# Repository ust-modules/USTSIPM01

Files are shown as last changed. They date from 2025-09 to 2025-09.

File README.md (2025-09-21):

# USTSIPM01 — Silicon photomultiplier (SiPM) interface module  

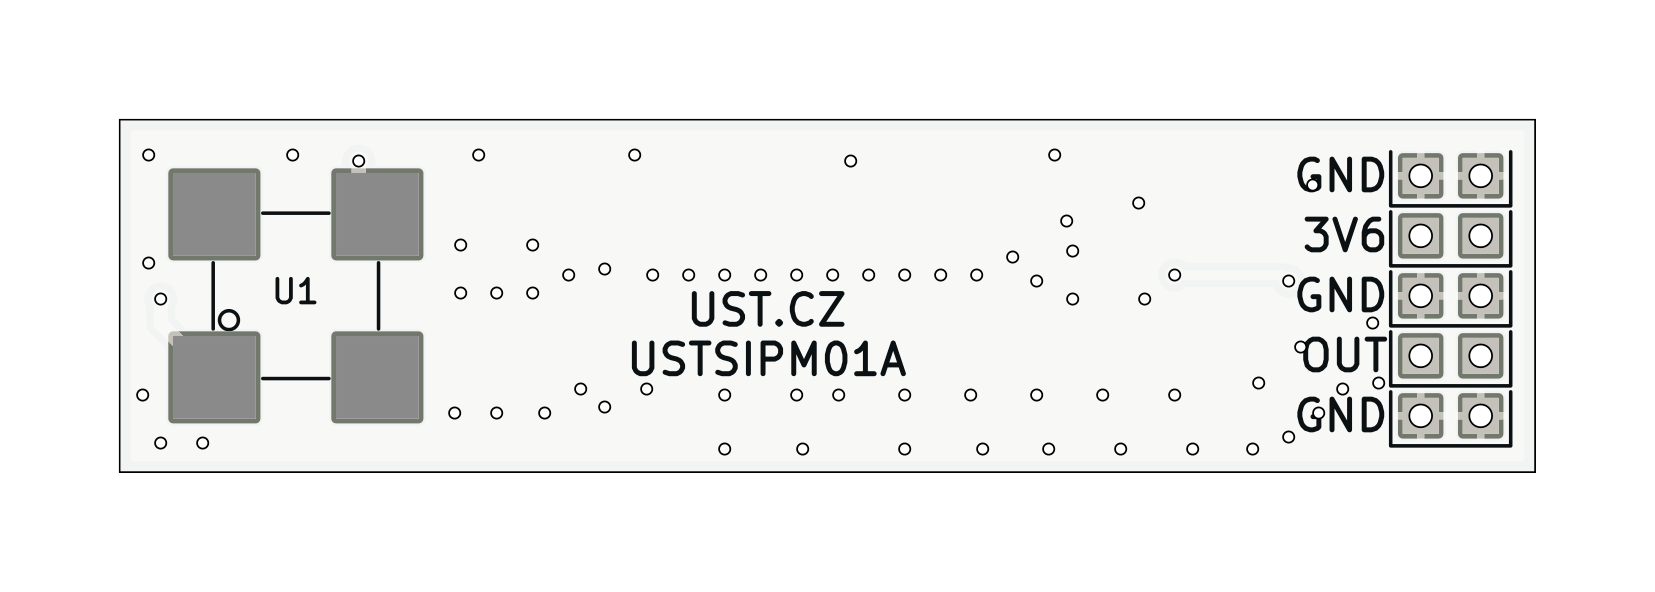
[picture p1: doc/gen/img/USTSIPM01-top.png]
Top view on USTSIPM01A

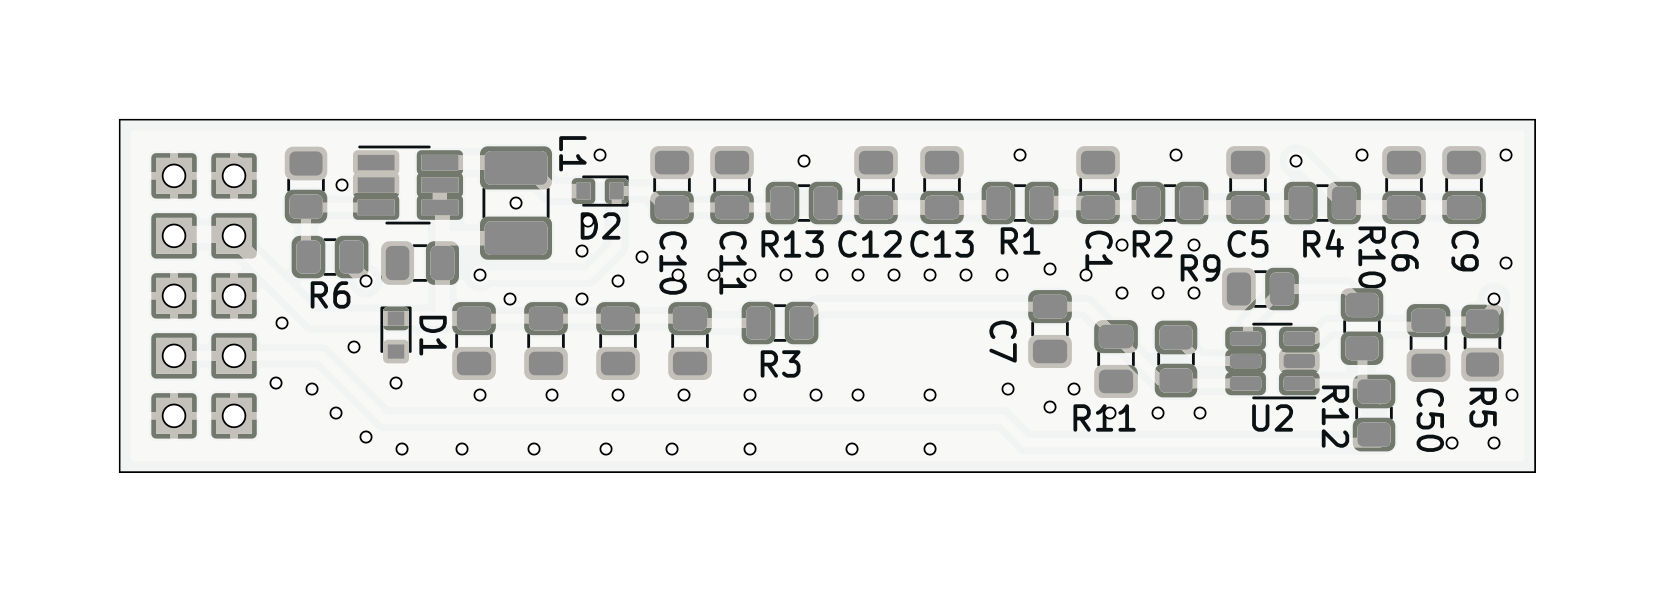
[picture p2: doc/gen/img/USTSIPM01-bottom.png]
Bottom view on USTSIPM01A


Complete analog front‑end for Silicon Photomultipliers (SiPM). The module provides resistor-configurable high‑voltage bias for the SiPM sensor and a low‑noise, wideband readout stage suitable for timing and amplitude measurements.

## Features

* Footprint for onsemi **MicroFC‑60035‑SMT** SiPM (6×6 mm, 35 µm microcells).
* On‑board high‑voltage boost converter MAX5026 generating the SiPM bias from the +5 V rail.
* Precision feedback network with design equation Vout = 1.25 V × (1 + R2/R3); default configuration targets to 31.7 V bias.
* Low‑noise **wideband amplifier** stage OPA836 for SiPM signal readout.
* Pin-header connector for lab bring‑up and diagnostics.

## Block Diagram

```mermaid
flowchart LR
    V["3V6"] -->|Bias supply| MAX5026["MAX5026 Boost"]
    MAX5026 -->|VBIAS 25-32 V| SiPM["SiPM MicroFC-60035"]
    SiPM -->|A| OPA836["OPA836 Readout"]
    OPA836 --> OUT["OUT"]
    V33["+3.3 V"] --> OPA836
```

## Electrical Characteristics (module)

* Supply rails: +3.6 V (bias converter), +3.3 V (analog stage).
* SiPM bias range: designable in \~25–32 V via resistor ratio (see below). Default assembly ≈ 31.7 V.
* Output: single‑ended, wideband path suitable for 50 Ω instrumentation (use external 50 Ω termination at scope/DAQ as required).

> Note (SiPM operating point): The sensor is biased at Vout = VBR + VOV, where VBR is the device’s breakdown voltage and VOV is the selected overvoltage. Typical recommended VOV = 1…5 V. Temperature coefficient of VBR ≈ +21.5 mV/°C (adjust bias accordingly).

## Bias Network Design

The MAX5026 feedback follows:

```
Vout = 1.25 V × (1 + R2/R3)
```

**Default population** (R2 = 3.9 MΩ, R3 = 160 kΩ) yields:

```
Vout ≈ 1.25 × (1 + 3.9M/160k) ≈ 31.7 V
```

**Example design** for MicroFC‑60035 with typical VBR ≈ 24.7 V:

* For **VOV = 3.0 V** → target **Vout ≈ 27.7 V**.
* Choose standard values to satisfy 1.25 × (1 + R2/R3) ≈ 27.7. For example, **R3 = 160 kΩ**, **R2 ≈ 3.394 MΩ** (use 3.40 MΩ or parallel combination). Verify with measurement on the assembled board.

> Keep the feedback resistors in the **MΩ** range to minimize divider current, and place them tight to the FB node. Use a low‑leakage layout around FB.
> Treat the SiPM and the module as **ESD‑sensitive**.

## Operating Guidance

* Start at low overvoltage (e.g., +1…2 V above the measured VBR) and increase gradually while monitoring dark count and pulse shape.
* Observe the maximum average current rating of the chosen sensor (for 6×6 mm devices typically tens of mA). Avoid saturating the device with continuous high optical flux.

## Changeable Parameters

* **SiPM bias (R2/R3):** select to set the required overvoltage window for the specific sensor lot and operating temperature.
* **OPA836 gain (R10/R12):** non‑inverting stage; A\_v = 1 + R10/R12. Default R10 = 12 kΩ, R12 = 1 kΩ → A\_v ≈ 13 V/V (\~22.3 dB). Adjust these resistors to set the desired voltage gain. (See schematic).

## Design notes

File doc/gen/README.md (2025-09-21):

# PCB

Board size: 60.0x15.0 mm (2.36x0.59 inches)

- This is the size of the rectangle that contains the board
- Thickness: 1.6 mm (63 mils)
- Material: FR4
- Finish: None
- Layers: 2
- Copper thickness: 35 µm

Solder mask: TOP / BOTTOM

- Color: Green

Silk screen: TOP / BOTTOM

- Color: White

Stackup:

| Name | Type | Color | Thickness [µm]| Material | Er | Loss tan |
|---|---|---|---|---|---|---|
| F.SilkS | Top Silk Screen | | | | | |
| F.Paste | Top Solder Paste | | | | | |
| F.Mask | Top Solder Mask | Green | 10 | | | |
| F.Cu | copper | | 35 | | | |
| dielectric 1 | core | | 1510 | FR4 | 4.5 | 0.020 |
| B.Cu | copper | | 35 | | | |
| B.Mask | Bottom Solder Mask | Green | 10 | | | |
| B.Paste | Bottom Solder Paste  | | | | | |
| B.SilkS | Bottom Silk Screen | | | | | |

# Important sizes

Clearance: 0.2 mm (8 mils)

Track width: 0.4 mm (16 mils)

- By design rules: 0.2 mm (8 mils)

Drill: 0.5 mm (20 mils)

- Vias: 0.5 mm (20 mils) [Design: 0.4 mm (16 mils)]
- Pads: 1.0 mm (39 mils)
- The above values are real drill sizes, they add 0.1 mm (4 mils) to plated holes (PTH)

Via: 0.8/0.4 mm (31/16 mils)

- By design rules: 0.4/0.3 mm (16/12 mils)
- Micro via: yes [0.2/0.1 mm (8/4 mils)]
- Buried/blind via: yes
- Total: 68 (thru: 68 buried/blind: 0 micro: 0)

Outer Annular Ring: 0.15 mm (6 mils)

- By design rules: 0.15 mm (6 mils)

Eurocircuits class: 4B
- Using min drill 0.5 mm for an OAR of 0.15 mm

# General stats

Components count: (SMD/THT)

- Top: 0/6 (THT)
- Bottom: 33/0 (SMD)

Defined tracks:

- 0.4 mm (16 mils)
- 0.5 mm (20 mils)
- 0.6 mm (24 mils)
- 0.8 mm (31 mils)
- 1.0 mm (39 mils)

Used tracks:

- 0.4 mm (16 mils) (55) defined: yes
- 0.6 mm (24 mils) (56) defined: yes

Defined vias:

- 0.8/0.4 mm (31/16 mils)

Used vias:

- 0.8/0.4 mm (31/16 mils) (Count: 68, Aspect: 2.0 A) defined: yes

Holes (excluding vias):

- 0.89 mm (35 mils) (10)

Oval holes:

Drill tools (including vias and computing adjusts and rounding):

- 0.5 mm (20 mils) (68)
- 1.0 mm (39 mils) (10)

Solder paste stats:

Using a paste with 87.75 % alloy, that has an specific gravity for the alloy of 7.4 g/cm³
and 1.0 g/cm³ for the flux. This paste has an specific gravity of  4.15 g/cm³.

The stencil thickness is  0.12 mm.

| Side | Pads with paste | Area [mm²] | Paste [g] |
|---|---|---|---|
| Top | 4 | 49.00 | 0.24 |
| Bottom | 74 | 97.40 | 0.48 |
| Total  | 78 | 146.40 | 0.73 |

Note: this is just an approximation to the theoretical value. Margins of the solder mask and waste aren't computed.

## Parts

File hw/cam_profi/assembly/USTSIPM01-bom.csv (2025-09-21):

Component | Description | Part | References | Value | Footprint | Quantity Per PCB | Datasheet | ust_id
1 | Unpolarized capacitor | C | C9 | 10nF | C_0805_2012Metric | 1 | ~ | 5c70984712875079b91f8b49
2 |  | C-Device | C11C12 | 100nF | C_0805_2012Metric | 2 |  | 5c70984712875079b91f8b4c
3 | Unpolarized capacitor | C | C5C6C8C50 | 100nF | C_0805_2012Metric | 4 | ~ | 5c70984712875079b91f8b4c
4 | Unpolarized capacitor | C | C3C4C7C14C15 | 10uF | C_0805_2012Metric | 5 | ~ | 5c70984712875079b91f8b53
5 |  | C-Device | C2 | 10uF | C_0805_2012Metric | 1 |  | 5c70984712875079b91f8b53
6 | Unpolarized capacitor | C | C1 | 10uF/35V | C_0805_2012Metric | 1 | ~ | 628d183cdc56076e9a223682
7 |  | C-Device | C10C13 | 1uF/50V | C_0805_2012Metric | 2 |  | 5c70984712875079b91f8b6f
8 |  | D_ZENER | D1 | BZX585-B5V6.115 | D_SOD-523 | 1 |  | 60879d38128750769ee58e48
9 |  | D_Schottky-Device | D2 | NSR05T40XV2T5G | D_SOD-523 | 1 | https://www.onsemi.com/pdf/datasheet/nsr05t40xv2-d.pdf | 5c70984712875079b91f8b7b
10 | 2x01 2.54 mm pitch header, 2 pins next to each other are connected | HEADER_2x01_PARALLEL | J4J5J6J8J9 | HEADER_2x01_PARALLEL | Straight_2x01 | 5
11 |  | L_Small-Device | L1 | 400uH cca 0,9mA NLV10JT391 | L_1210_3225Metric_Pad1.42x2.65mm_HandSolder | 1 |  | 628d18f5dc56076e9a2236a9
12 | Resistor | R | R2R4R5 | 10R | R_0805_2012Metric | 3 | ~ | 5c70984512875079b91f896d
13 | Resistor | R | R1R3 | 100R | R_0805_2012Metric | 2 | ~ | 5c70984512875079b91f8977
14 |  | R-Device | R13 | 100R | R_0805_2012Metric | 1 |  | 5c70984512875079b91f8977
15 | Resistor | R | R9 | 470R | R_0805_2012Metric | 1 | ~ | 5c70984512875079b91f8986
16 | Resistor | R | R12 | 1k | R_0805_2012Metric | 1 | ~ | 5c70984512875079b91f898c
17 | Resistor | R | R11 | 10k | R_0805_2012Metric | 1 | ~ | 5c70984612875079b91f899f
18 | Resistor | R | R10 | 12k | R_0805_2012Metric | 1 | ~ | 5c70984612875079b91f89a1
19 |  | R-Device | R7 | 160k | R_0805_2012Metric | 1 |  | 628d19e8dc56076e9a2236eb
20 |  | R-Device | R6 | 3M9 | R_0805_2012Metric | 1 |  | 62c7d4f48c8e243169d1938e
21 |  | MAX5026-MLAB_IO | U3 | MAX5026 | SOT-23-6_Handsoldering | 1 | https://datasheets.maximintegrated.com/en/ds/MAX5025-MAX5028.pdf | 5c70984712875079b91f8b7c
22 |  | MICROFC-60035-SMT-TR(1) | U1 | MICROFC-60035-SMT-TR(1) | MicroFC−60035−SMT | 1 | https://www.onsemi.com/pdf/datasheet/microc-series-d.pdf | 60f907411287500165a96c1e
23 | Single Low-Power, 3.9GHz, Wideband, Ultra-Low Noise, Voltage-Feedback Operational Amplifier with Disable, SOT-23-6 | OPA847xDBV | U2 | OPA836IDB | SOT-23-6 | 1 | https://www.ti.com/lit/ds/symlink/opa836.pdf | 5c7273171287500b4e112ff8

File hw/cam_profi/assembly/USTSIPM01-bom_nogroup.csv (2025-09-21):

Component | Description | Part | References | Value | Footprint | Quantity Per PCB | Datasheet | ust_id
1 | Unpolarized capacitor | C | C9 | 10nF | C_0805_2012Metric | 1 | ~ | 5c70984712875079b91f8b49
2 |  | C-Device | C11 | 100nF | C_0805_2012Metric | 1 |  | 5c70984712875079b91f8b4c
3 |  | C-Device | C12 | 100nF | C_0805_2012Metric | 1 |  | 5c70984712875079b91f8b4c
4 | Unpolarized capacitor | C | C5 | 100nF | C_0805_2012Metric | 1 | ~ | 5c70984712875079b91f8b4c
5 | Unpolarized capacitor | C | C50 | 100nF | C_0805_2012Metric | 1 | ~ | 5c70984712875079b91f8b4c
6 | Unpolarized capacitor | C | C6 | 100nF | C_0805_2012Metric | 1 | ~ | 5c70984712875079b91f8b4c
7 | Unpolarized capacitor | C | C8 | 100nF | C_0805_2012Metric | 1 | ~ | 5c70984712875079b91f8b4c
8 | Unpolarized capacitor | C | C14 | 10uF | C_0805_2012Metric | 1 | ~ | 5c70984712875079b91f8b53
9 | Unpolarized capacitor | C | C15 | 10uF | C_0805_2012Metric | 1 | ~ | 5c70984712875079b91f8b53
10 |  | C-Device | C2 | 10uF | C_0805_2012Metric | 1 |  | 5c70984712875079b91f8b53
11 | Unpolarized capacitor | C | C3 | 10uF | C_0805_2012Metric | 1 | ~ | 5c70984712875079b91f8b53
12 | Unpolarized capacitor | C | C4 | 10uF | C_0805_2012Metric | 1 | ~ | 5c70984712875079b91f8b53
13 | Unpolarized capacitor | C | C7 | 10uF | C_0805_2012Metric | 1 | ~ | 5c70984712875079b91f8b53
14 | Unpolarized capacitor | C | C1 | 10uF/35V | C_0805_2012Metric | 1 | ~ | 628d183cdc56076e9a223682
15 |  | C-Device | C10 | 1uF/50V | C_0805_2012Metric | 1 |  | 5c70984712875079b91f8b6f
16 |  | C-Device | C13 | 1uF/50V | C_0805_2012Metric | 1 |  | 5c70984712875079b91f8b6f
17 |  | D_ZENER | D1 | BZX585-B5V6.115 | D_SOD-523 | 1 |  | 60879d38128750769ee58e48
18 |  | D_Schottky-Device | D2 | NSR05T40XV2T5G | D_SOD-523 | 1 | https://www.onsemi.com/pdf/datasheet/nsr05t40xv2-d.pdf | 5c70984712875079b91f8b7b
19 | 2x01 2.54 mm pitch header, 2 pins next to each other are connected | HEADER_2x01_PARALLEL | J4 | HEADER_2x01_PARALLEL | Straight_2x01 | 1
20 | 2x01 2.54 mm pitch header, 2 pins next to each other are connected | HEADER_2x01_PARALLEL | J5 | HEADER_2x01_PARALLEL | Straight_2x01 | 1
21 | 2x01 2.54 mm pitch header, 2 pins next to each other are connected | HEADER_2x01_PARALLEL | J6 | HEADER_2x01_PARALLEL | Straight_2x01 | 1
22 | 2x01 2.54 mm pitch header, 2 pins next to each other are connected | HEADER_2x01_PARALLEL | J8 | HEADER_2x01_PARALLEL | Straight_2x01 | 1
23 | 2x01 2.54 mm pitch header, 2 pins next to each other are connected | HEADER_2x01_PARALLEL | J9 | HEADER_2x01_PARALLEL | Straight_2x01 | 1
24 |  | L_Small-Device | L1 | 400uH cca 0,9mA NLV10JT391 | L_1210_3225Metric_Pad1.42x2.65mm_HandSolder | 1 |  | 628d18f5dc56076e9a2236a9
25 | Resistor | R | R2 | 10R | R_0805_2012Metric | 1 | ~ | 5c70984512875079b91f896d
26 | Resistor | R | R4 | 10R | R_0805_2012Metric | 1 | ~ | 5c70984512875079b91f896d
27 | Resistor | R | R5 | 10R | R_0805_2012Metric | 1 | ~ | 5c70984512875079b91f896d
28 | Resistor | R | R1 | 100R | R_0805_2012Metric | 1 | ~ | 5c70984512875079b91f8977
29 |  | R-Device | R13 | 100R | R_0805_2012Metric | 1 |  | 5c70984512875079b91f8977
30 | Resistor | R | R3 | 100R | R_0805_2012Metric | 1 | ~ | 5c70984512875079b91f8977
31 | Resistor | R | R9 | 470R | R_0805_2012Metric | 1 | ~ | 5c70984512875079b91f8986
32 | Resistor | R | R12 | 1k | R_0805_2012Metric | 1 | ~ | 5c70984512875079b91f898c
33 | Resistor | R | R11 | 10k | R_0805_2012Metric | 1 | ~ | 5c70984612875079b91f899f
34 | Resistor | R | R10 | 12k | R_0805_2012Metric | 1 | ~ | 5c70984612875079b91f89a1
35 |  | R-Device | R7 | 160k | R_0805_2012Metric | 1 |  | 628d19e8dc56076e9a2236eb
36 |  | R-Device | R6 | 3M9 | R_0805_2012Metric | 1 |  | 62c7d4f48c8e243169d1938e
37 |  | MAX5026-MLAB_IO | U3 | MAX5026 | SOT-23-6_Handsoldering | 1 | https://datasheets.maximintegrated.com/en/ds/MAX5025-MAX5028.pdf | 5c70984712875079b91f8b7c
38 |  | MICROFC-60035-SMT-TR(1) | U1 | MICROFC-60035-SMT-TR(1) | MicroFC−60035−SMT | 1 | https://www.onsemi.com/pdf/datasheet/microc-series-d.pdf | 60f907411287500165a96c1e
39 | Single Low-Power, 3.9GHz, Wideband, Ultra-Low Noise, Voltage-Feedback Operational Amplifier with Disable, SOT-23-6 | OPA847xDBV | U2 | OPA836IDB | SOT-23-6 | 1 | https://www.ti.com/lit/ds/symlink/opa836.pdf | 5c7273171287500b4e112ff8

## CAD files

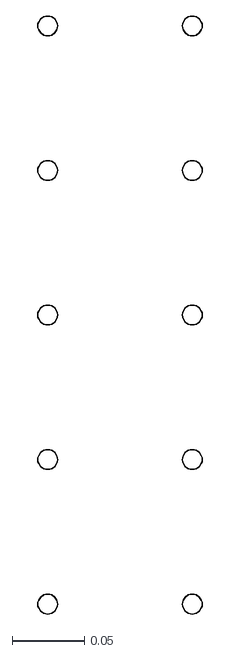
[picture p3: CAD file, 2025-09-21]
doc/gen/dxf/USTSIPM01-User_Eco2.dxf
0.114 x 0.414

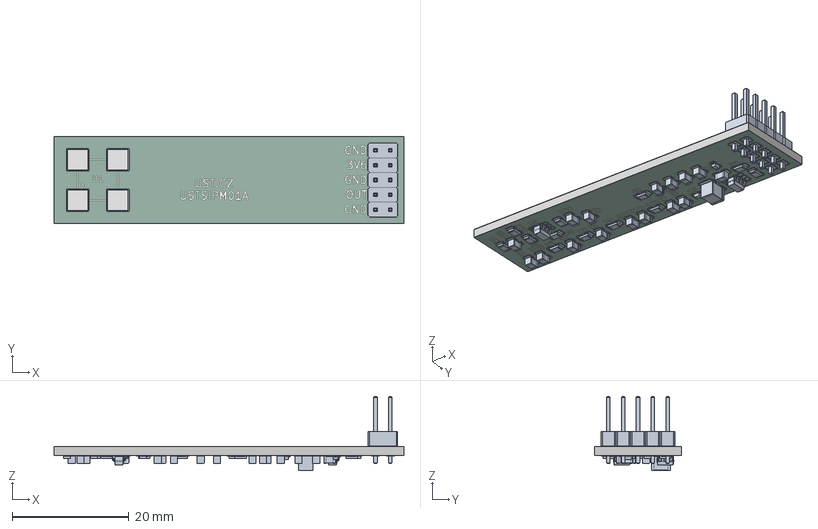
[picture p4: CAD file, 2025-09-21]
doc/gen/mesh/USTSIPM01.step
60.0 x 15.0 x 12.7 mm
PinHeader_2x01_P2.54mm_Vertical x 5
R_0805_2012Metric x 12
C_0805_2012Metric x 16
L_1210_3225Metric
D_SOD-523 x 2
SOT-23-6 x 2
kibot_wx7303fz_copper
kibot_wx7303fz_pad
kibot_wx7303fz_via
kibot_wx7303fz_silkscreen
kibot_wx7303fz_soldermask
kibot_wx7303fz_PCB

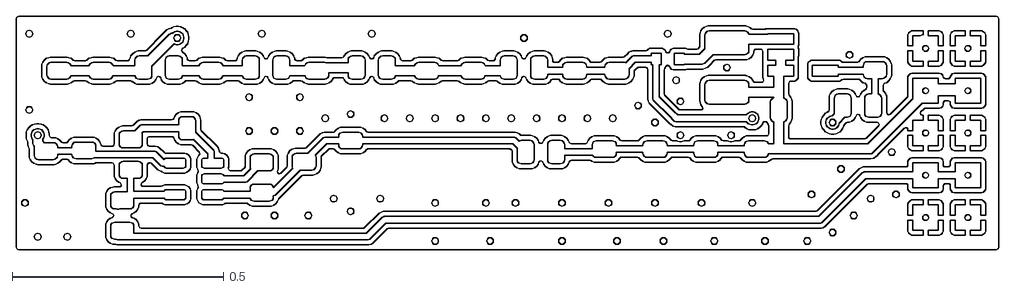
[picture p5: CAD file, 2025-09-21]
doc/gen/dxf/USTSIPM01-B_Cu.dxf
2.32 x 0.551

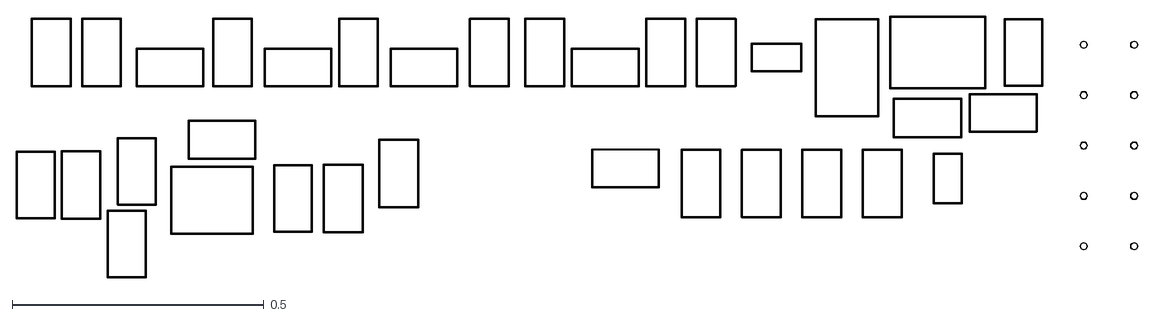
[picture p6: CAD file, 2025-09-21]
doc/gen/dxf/USTSIPM01-B_Courtyard.dxf
2.23 x 0.519

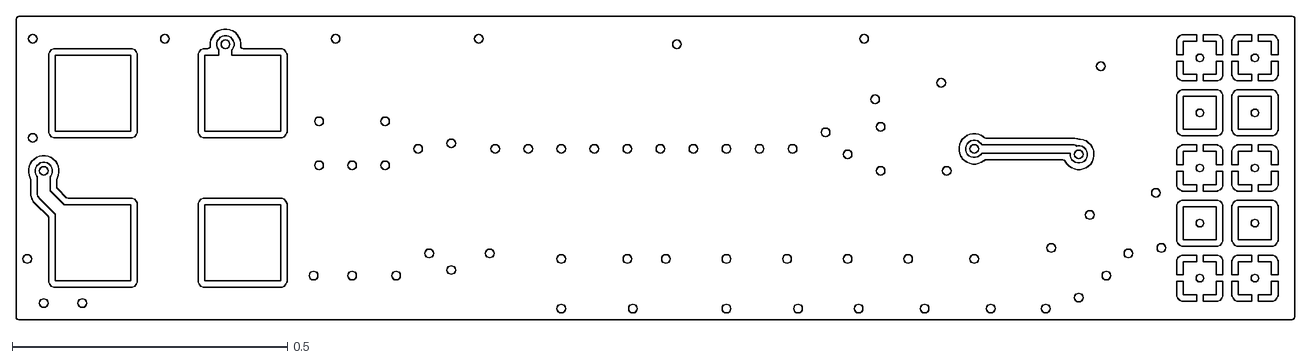
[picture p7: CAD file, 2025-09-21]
doc/gen/dxf/USTSIPM01-F_Cu.dxf
2.32 x 0.551

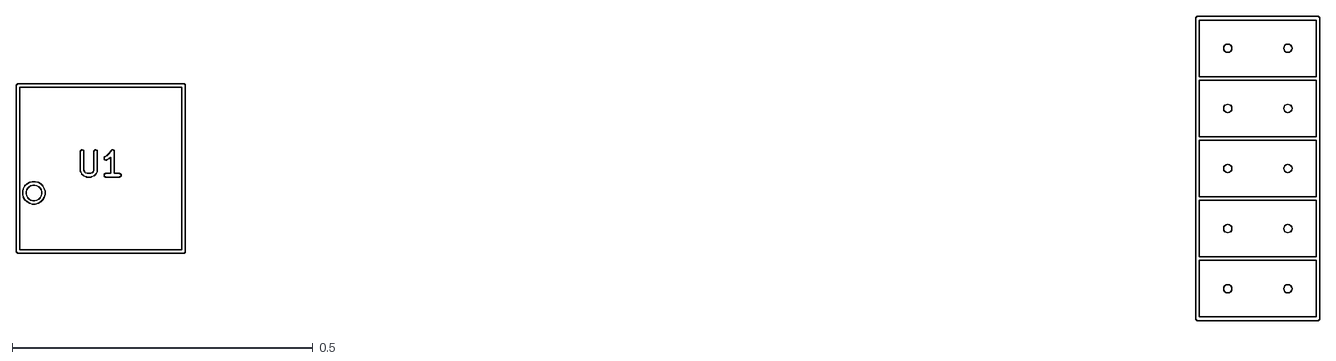
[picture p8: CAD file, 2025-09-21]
doc/gen/dxf/USTSIPM01-F_Fab.dxf
2.17 x 0.506

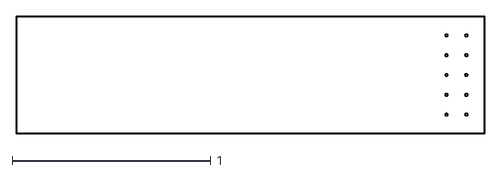
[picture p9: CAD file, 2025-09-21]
doc/gen/dxf/USTSIPM01-Edge_Cuts.dxf
2.36 x 0.593

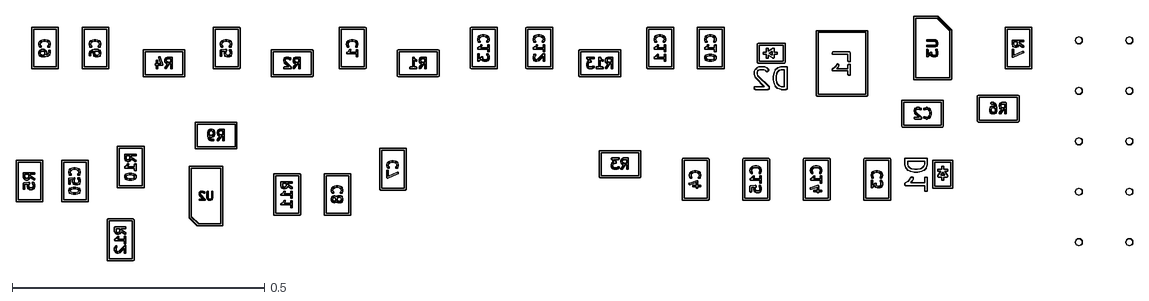
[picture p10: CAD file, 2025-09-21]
doc/gen/dxf/USTSIPM01-B_Fab.dxf
2.21 x 0.484

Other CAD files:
doc/gen/dxf/USTSIPM01-B_Adhesive.dxf
doc/gen/dxf/USTSIPM01-F_Adhesive.dxf
doc/gen/dxf/USTSIPM01-B_Mask.dxf
doc/gen/dxf/USTSIPM01-B_Paste.dxf
doc/gen/dxf/USTSIPM01-B_Silkscreen.dxf
doc/gen/dxf/USTSIPM01-F_Mask.dxf
doc/gen/dxf/USTSIPM01-F_Paste.dxf
doc/gen/dxf/USTSIPM01-F_Silkscreen.dxf
doc/gen/mesh/USTSIPM01.stl

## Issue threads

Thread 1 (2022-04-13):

Popis

ChroustJan, 2022-04-13:
PCB má vzniknout spojením dvou modulů:
https://github.com/mlab-modules/STEPUPDC01
https://github.com/mlab-modules/SIPM02

U měniče je potřeba vyměnit cívka. 400uH (proud cca 0,9mA).  odporovej delic 3M9 / 160k
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

kaklik, 2022-05-25:
Tohle issue se mi nezdá kompletní. Respektive se asi zapomíná na [dřívější poznatky z geodosů](https://github.com/mlab-modules/PCRD06/issues).  Zejména asi jde o [snazší výrobu při spojování modulů](https://github.com/mlab-modules/PCRD06/issues/3).

kaklik, 2022-08-04:
Tenhle nekompletní popis přestal být relevantní.

Closed 2022-08-04.

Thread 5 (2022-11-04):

Rigid-flex PCB

kaklik, 2022-11-04:
Pro lepší mechanickou konstrukci by bylo vhodné, aby připojovací konektor nebyl mechanicky spojený s křemíkovým fotonásobičem u scintilátoru. Tj. aby mechanické namáhání konektoru nemělo vliv na pozici scintilátoru vůči fotonásobiči.

Taktéž je potřeba elektrické signály od fotonásobiče odvést meandrem, který zajistí, že se k fotonásobiči nedostane nežádoucí světlo.

Obě tyto podmínky je myslím možné splnit použitím [rigid-flex](https://www.gatemapcb.com/flex-rigid-pcb) plošného spoje, tak že konektory společně s částí elektroniky budou na vzdáleném PCB, které bude s PCB na kterém je umístěn křemíkový fotonásobič spojen flexibilním páskem.
Flexibilní pásek pak bude možné z pouzdra krystalu odvést meandrem.

kaklik, 2023-02-02:
Pro návrh takového PCB se zřejmě bude hodit tenhle plugin do KiCADu, který umí kreslit zaoblené cesty: https://github.com/mitxela/kicad-round-tracks

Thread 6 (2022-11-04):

Temperature sensor

kaklik, 2022-11-04:
Jak scintilátor, tak i křemíkový fotonásobič jsou součástky, kterým se mění jejich detekční vlastnosti s teplotou.
Je proto vhodné obou těchto komponent měřit teplotu. Nejmenším čidlem by v tomto případě mohla být obyčejná křemíková dioda se zdrojem proudu. Takové řešení by mohlo být kompatibilní s [potřebou měření teploty u křemíkových detektorů](https://github.com/ust-modules/USTSIPIN02/issues/7).

V ideálním případě by celý měřící blok měl obsahovat dvě diody, jednu poblíž křemíkového fotonásobiče a druhou na pásku rigid-flex #5 spoje, která by sloužila pro měření teploty scintilátoru.

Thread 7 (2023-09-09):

DC coupling to PCRD06?

kaklik, 2023-09-09:
Připadá mi podivné, že jak USTSIPM01

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

Tak i PCRD06

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

Nemá žádnou střídavou vazbu. Což znamená, že nedochází k oddělení DC offsetu a ten se v celém zapojení bude sčítat. Kromě různých offsetů v různých vyrobených kusech to bude myslím si mít i vliv na kalibraci.

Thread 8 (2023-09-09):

Temperature correction?

kaklik, 2023-09-09:
Tady jsem našel [zapojení](https://github.com/OpenGammaProject/MicroFC-SiPM-Carrier-Board/blob/main/hardware/schematic.pdf), které provádí teplotní korekci citlivosti SiPM.

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

Důležité taky je, že k vytvoření napájecího napětí se [používá úplně stejný obvod](https://github.com/OpenGammaProject/Mini-SiD/blob/main/hardware/schematic.pdf), jako zde u USTSIPM01.

Nejsem si jistý, jestli zapojení je teplotní korekce měniče, nebo fotonásobiče. Každopádně to má vliv na #6

kaklik, 2023-09-09:
Tak podle [datasheetu k SiPM](https://www.onsemi.com/pdf/datasheet/microc-series-d.pdf) je to zjevně teplotní korekce průrazného napětí diod SiPM.  Taková korekce dává docela smysl, protože něco takového zřejmě nejde moc dobře zohlednit ve zpracování dat.

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

kaklik, 2023-09-14:
Použitelná řešení tohoto stavu vidím dvě:

1. Vyhřívat sestavu fotonásobiče a scintilátoru na nějakou konstantní teplotu (Tohle bude zvlášť v zimě energeticky náročné)
2. Nějak řídit bias napětí na SiPM (Možná použitím I2C trimru)

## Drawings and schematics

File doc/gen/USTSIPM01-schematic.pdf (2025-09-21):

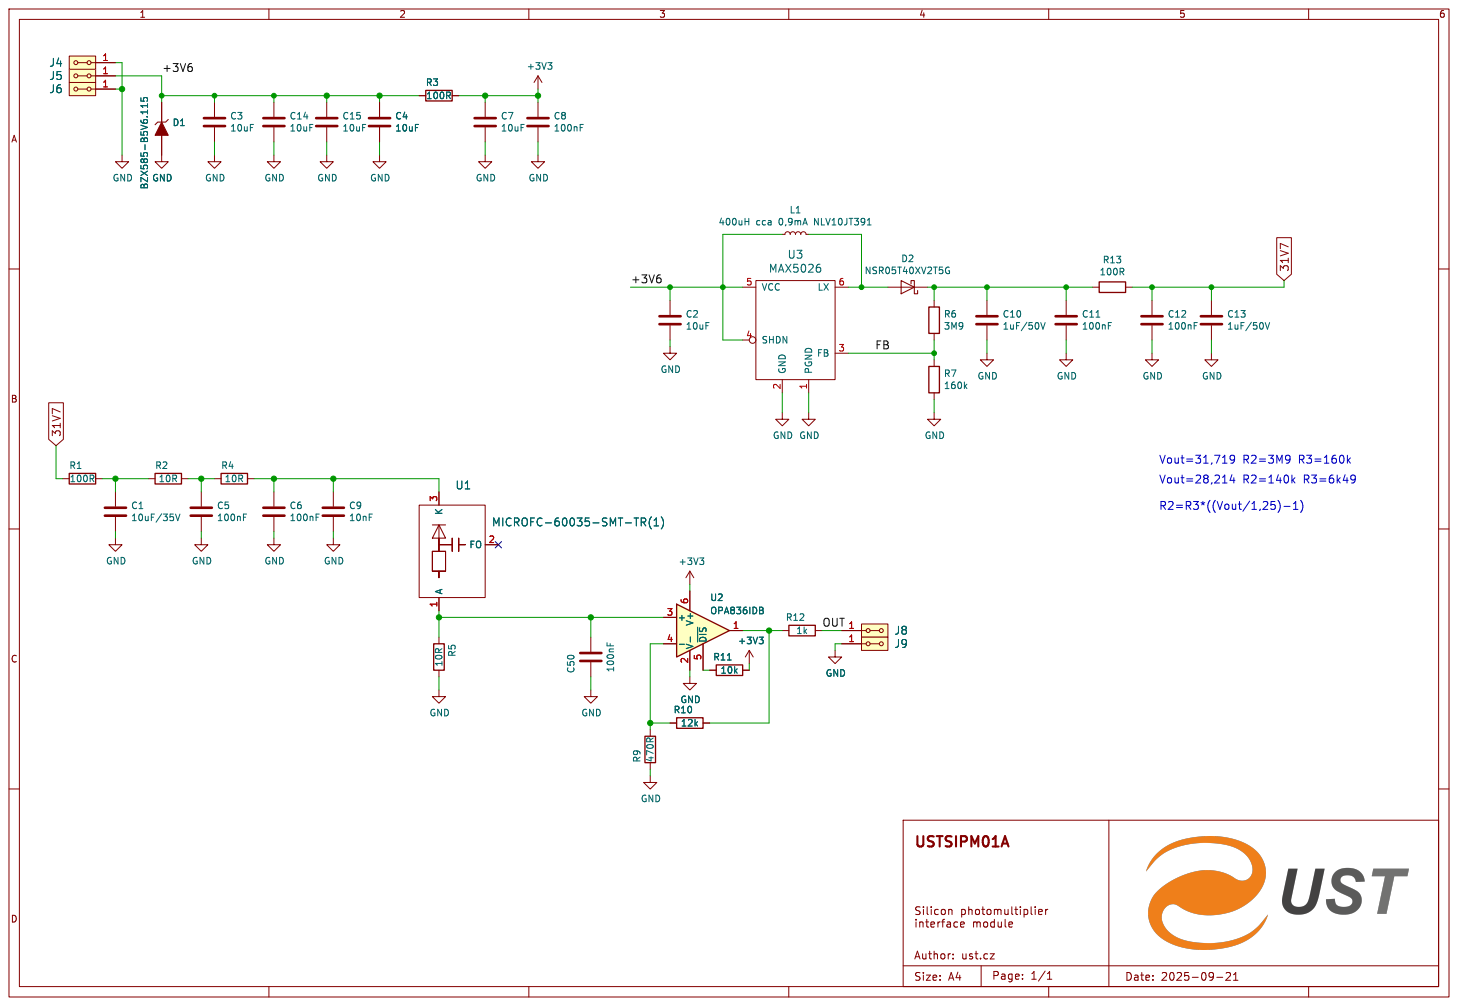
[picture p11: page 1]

3 FO 2 U1 MICROFC-60035-SMT-TR(1) GND GND GND

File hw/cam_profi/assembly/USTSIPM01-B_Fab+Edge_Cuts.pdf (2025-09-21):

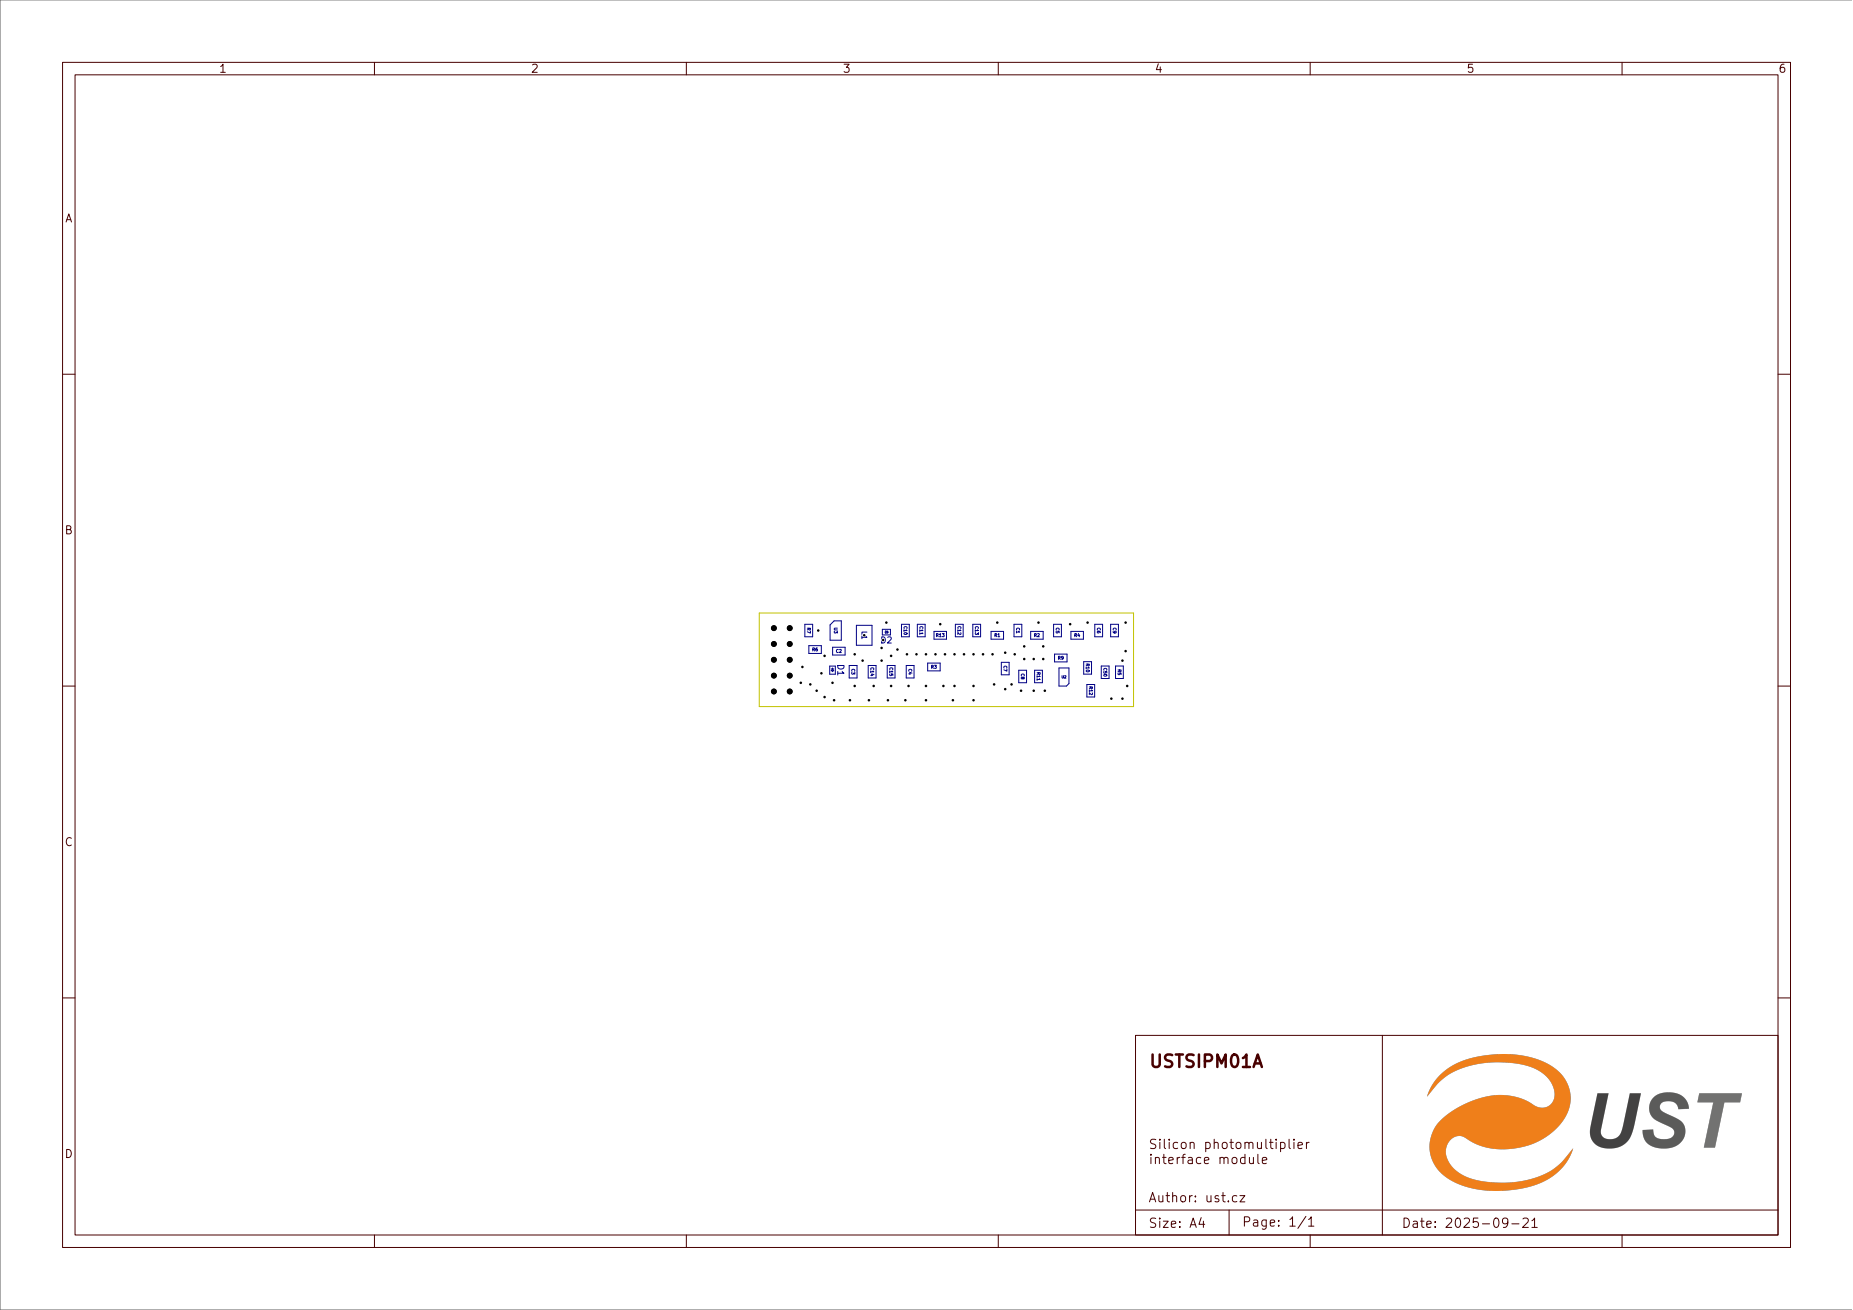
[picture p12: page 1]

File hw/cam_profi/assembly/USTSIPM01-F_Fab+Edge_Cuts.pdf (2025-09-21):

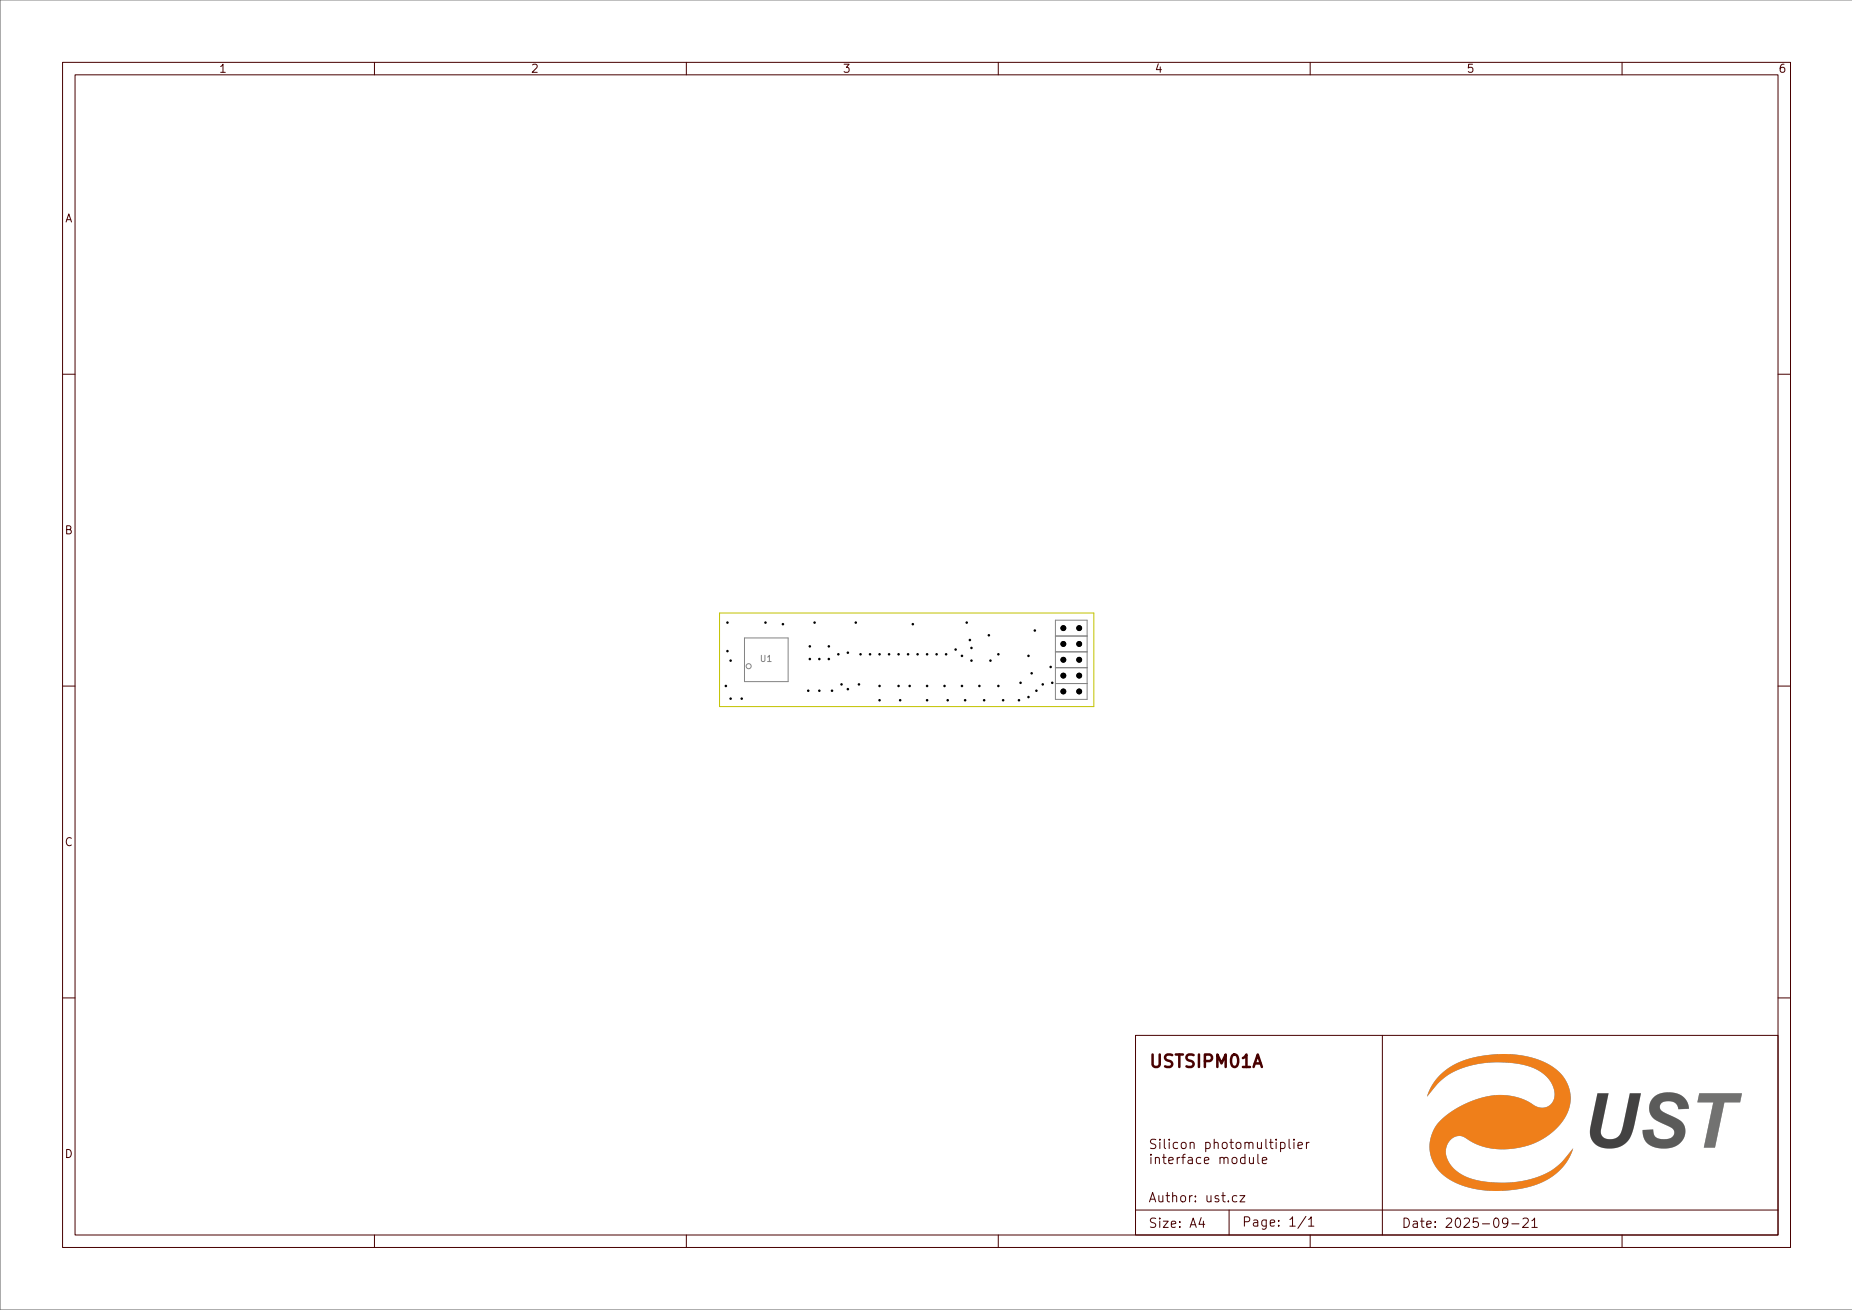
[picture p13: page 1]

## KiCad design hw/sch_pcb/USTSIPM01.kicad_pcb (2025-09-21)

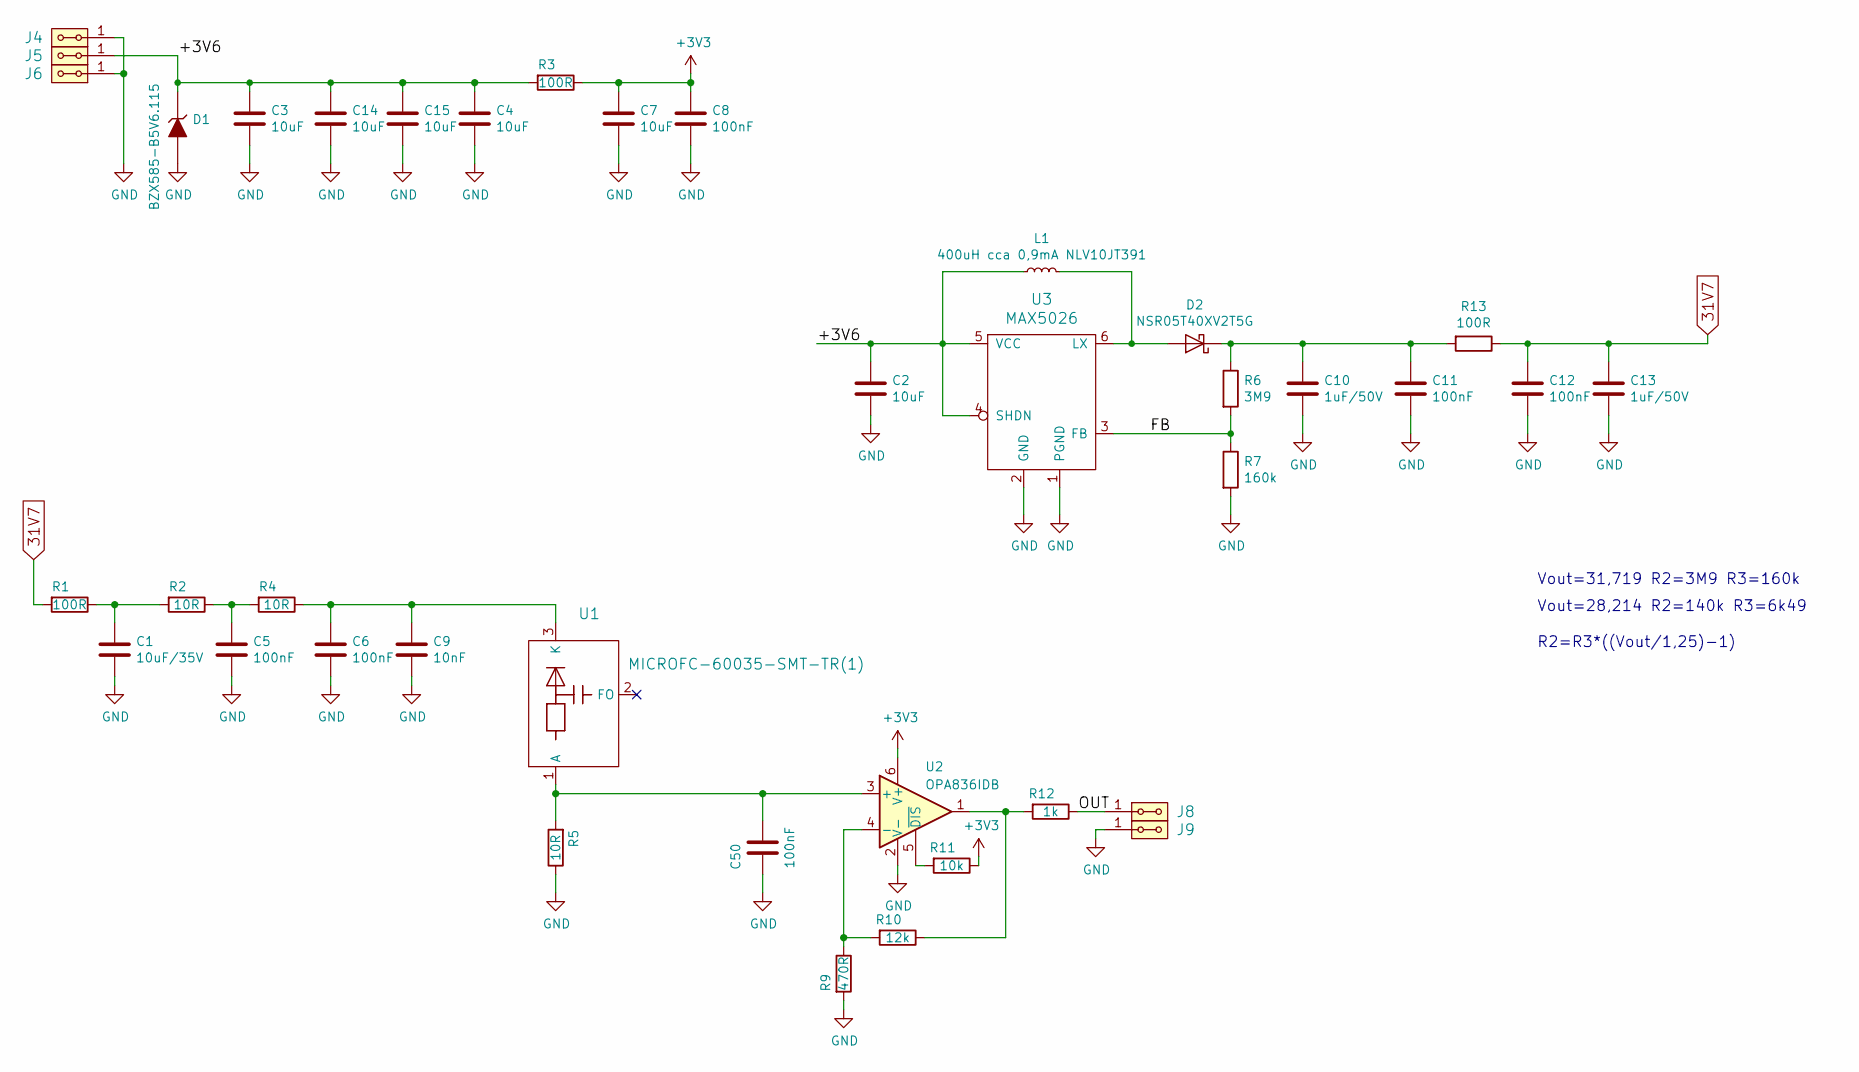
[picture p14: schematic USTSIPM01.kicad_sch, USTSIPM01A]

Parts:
C1: 10uF/35V; C_0805_2012Metric
C2, C3, C4, C7, C14, C15: 10uF; C_0805_2012Metric
C5, C6, C8, C11, C12, C50: 100nF; C_0805_2012Metric
C9: 10nF; C_0805_2012Metric
C10, C13: 1uF/50V; C_0805_2012Metric
D1: BZX585-B5V6.115; D_SOD-523
D2: NSR05T40XV2T5G; D_SOD-523
J4, J5, J6, J8, J9: HEADER_2x01_PARALLEL; Straight_2x01
L1: 400uH cca 0,9mA NLV10JT391; L_1210_3225Metric_Pad1.42x2.65mm_HandSolder
R1, R3, R13: 100R; R_0805_2012Metric
R2, R4, R5: 10R; R_0805_2012Metric
R6: 3M9; R_0805_2012Metric
R7: 160k; R_0805_2012Metric
R9: 470R; R_0805_2012Metric
R10: 12k; R_0805_2012Metric
R11: 10k; R_0805_2012Metric
R12: 1k; R_0805_2012Metric
U1: MICROFC-60035-SMT-TR(1); MicroFC−60035−SMT
U2: OPA836IDB; SOT-23-6
U3: MAX5026; SOT-23-6_Handsoldering

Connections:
31V7: C12.1, C13.1, R1.2, R13.1
+3V3: C7.1, C8.1, R3.1, R11.1, U2.6 (V+)
/+3V6: C2.1, C3.1, C4.1, C14.1, C15.1, D1.1 (K), J5.1, J5.2, L1.1, R3.2, U3.4 (SHDN), U3.5 (VCC)
/FB: R6.2, R7.1, U3.3 (FB)
/OUT: J8.1, J8.2, R12.1
GND: C1.2, C2.2, C3.2, C4.2, C5.2, C6.2, C7.2, C8.2, C9.2, C10.2, C11.2, C12.2, C13.2, C14.2, C15.2, C50.2, D1.2 (A), J4.1, J4.2, J6.1, J6.2, J9.1, J9.2, R5.1, R7.2, R9.2, U2.2 (V-), U3.1 (PGND), U3.2 (GND)
unnamed: C1.1, R1.1, R2.2
unnamed: C5.1, R2.1, R4.2
unnamed: D2.2 (A), L1.2, U3.6 (LX)
unnamed: C10.1, C11.1, D2.1 (K), R6.1, R13.2
unnamed: R10.1, R12.2, U2.1
unnamed: C50.1, R5.2, U1.1 (A), U2.3 (+)
unnamed: C6.1, C9.1, R4.1, U1.3 (K)
unnamed: R9.1, R10.2, U2.4 (-)
unnamed: R11.2, U2.5 (~DIS)

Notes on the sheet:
Vout=28,214 R2=140k R3=6k49
R2=R3*((Vout/1,25)-1)
Vout=31,719 R2=3M9 R3=160k

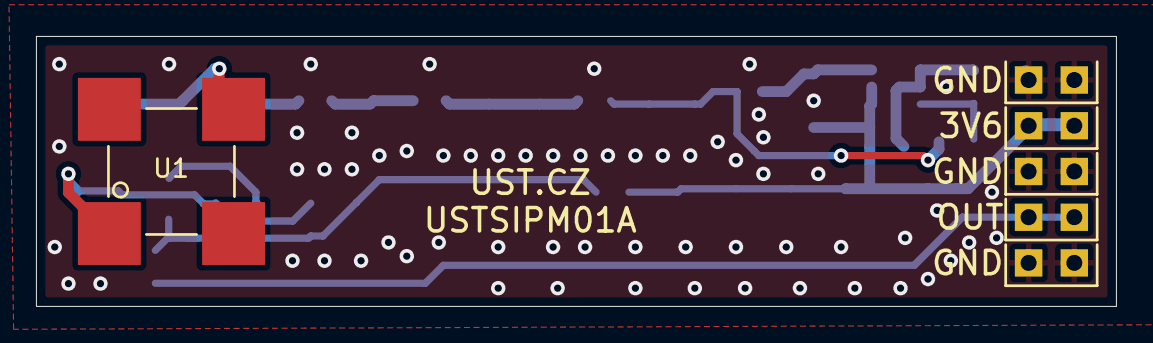
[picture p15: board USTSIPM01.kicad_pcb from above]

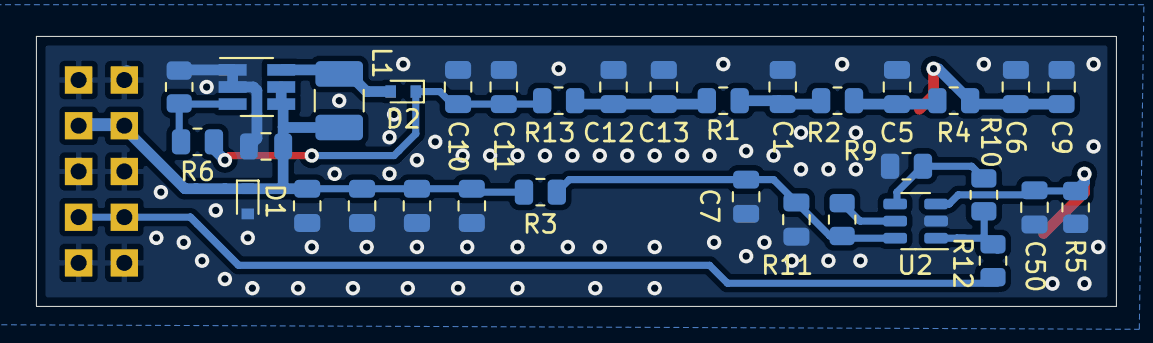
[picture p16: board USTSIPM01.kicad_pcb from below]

Board: 2 copper layers, 60.0 x 15.0 mm, 39 parts (33 on the bottom side), 15 nets.

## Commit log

2022-05-05 Edit schema
    [USTSIPM01A.kicad_pcb, USTSIPM01A.kicad_sch]
2022-05-05 Update actions products
    [USTSIPM01A-B_Adhesive.dxf, USTSIPM01A-B_Courtyard.dxf, USTSIPM01A-B_Cu.dxf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]
2022-05-16 Editing schema and PCB
    [USTSIPM01A.kicad_pcb, USTSIPM01A.kicad_sch]
2022-05-17 Editing PCB
    [USTSIPM01A.kicad_pcb, USTSIPM01A.kicad_sch]
2022-05-21 Edit PCB
    [USTSIPM01A.kicad_pcb]
2022-05-24 Priprava vyrobnich dat
    [USTSIPM01A.kicad_pcb, USTSIPM01A.kicad_sch]
2022-07-08 Edit UST ID for 3M9
    [USTSIPM01A.kicad_sch]
2022-08-04 Update title block fields.
    [USTSIPM01A.kicad_sch]
2023-09-09 Add a link to datasheet.
    [USTSIPM01A.kicad_sch]
2025-09-21 Update project to KiCAD9
    [USTSIPM01.kicad_pcb, USTSIPM01.kicad_sch, USTSIPM01A.kicad_pcb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]
2025-09-21 Align schematics symbols to grid. Update PCB from schematic. Improve silkscreen. Move PCB to center of the page.
    [USTSIPM01.kicad_pcb, USTSIPM01.kicad_sch]
